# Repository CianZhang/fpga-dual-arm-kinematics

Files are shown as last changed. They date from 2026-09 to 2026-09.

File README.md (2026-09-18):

# 双机械臂机械结构设计与 FPGA 逆运动学实现

**Mechanical Design and FPGA Inverse Kinematics for a Dual-Arm Robot**

**第九届全国大学生集成电路创新创业大赛全国二等奖作品**

在这个项目中，我的主要工作是基于现有 STL 方案的机械结构补充设计，以及 Delta 并联机械臂和平行四边形连杆机械臂的逆运动学 FPGA 实现。本仓库围绕结构参数、数学模型、Verilog 定点计算与实物系统之间的对应关系整理。

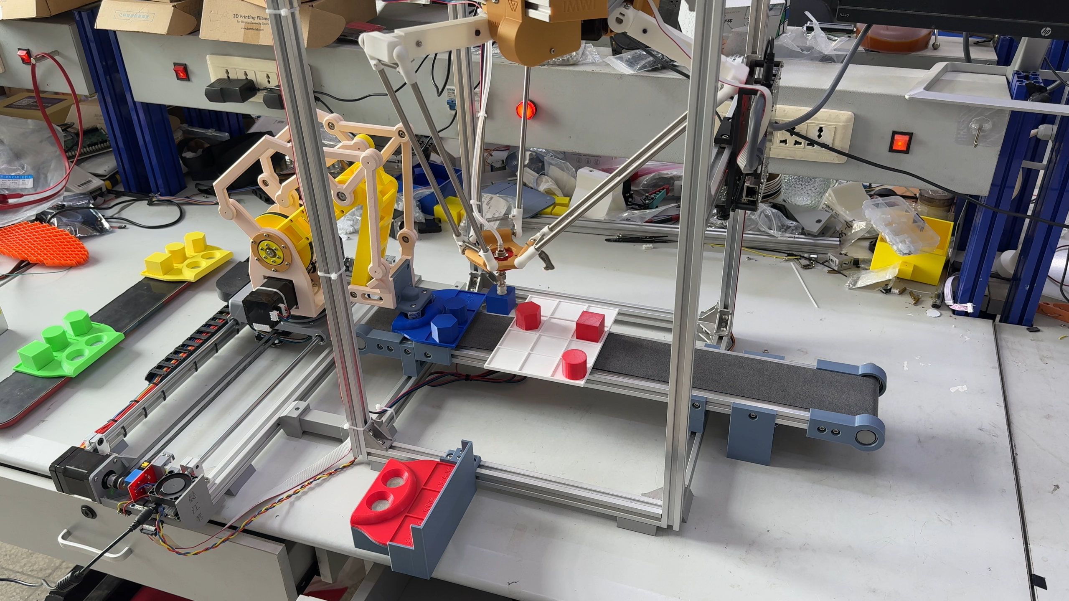
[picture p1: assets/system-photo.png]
双机械臂分拣系统实物，摘自比赛设计报告


> 摄像头采集与 FPGA 视觉识别由其他团队成员完成，本仓库保留运动控制侧的接口和系统背景，不包含视觉工程源码。两套机构基于网络 STL 方案，我补充了部分结构；仓库收录本人建模的 SolidWorks 源文件，详见[贡献与来源](docs/contributions.md)。

## 主要工作

- **机械结构补充设计**：基于网络 STL 机构方案补充结构并完成 SolidWorks 建模，结合分拣任务进行安装与配套设计。结构参数与解算代码对照展示。
- **两类机械臂逆运动学**：将目标空间坐标转换为驱动关节角度，再连接步进电机控制模块。
- **定点运算实现**：以整数缩放、位宽规划和移位处理实现原本的浮点计算；Delta 输入坐标采用 ×16 编码，电机角度采用 ×256 编码。
- **资源复用**：通过状态机调度乘法器，配合迭代开方和串行 CORDIC，在资源与计算延迟之间进行取舍。

仓库同时保存原项目中的线性插补、电机控制和串口等配套模块，以便理解完整调用链；这些文件的收录不代表其中每一行都是独立原创。

## 系统关系

```mermaid
flowchart LR
    V[视觉识别板
其他团队成员实现] -->|UART 识别结果| C[分拣与路径控制]
    U[上位机指令] --> C
    C --> D[Delta 逆运动学]
    C --> L[连杆机械臂逆运动学]
    D --> M[步进电机脉冲与方向]
    L --> M
    M --> H[双机械臂与平移机构]
```

## 结果与证据

以下 FPGA 数据来自比赛设计报告，是历史仿真与工程记录，并非本次重新上板测得。

| 项目 | 原报告结果 | 解释 |
| --- | --- | --- |
| Delta 完整逆解 | 50 MHz，235 个周期，约 4.7 μs | 算法解算耗时，不是机械臂完成运动的时间 |
| 单点角度对比 | 约 0.0048° 差异 | 坐标 (0, 0, −237.5 mm)，不是全工作空间最大误差 |
| 两套逆解算术资源 | 报告记录为 16 APM | 整机资源图显示 30/30 APM，不能混用统计范围 |
| 机械结构与实物 | 装配图、尺寸图、实物图 | CAD 来源与版本状态见 mechanical |

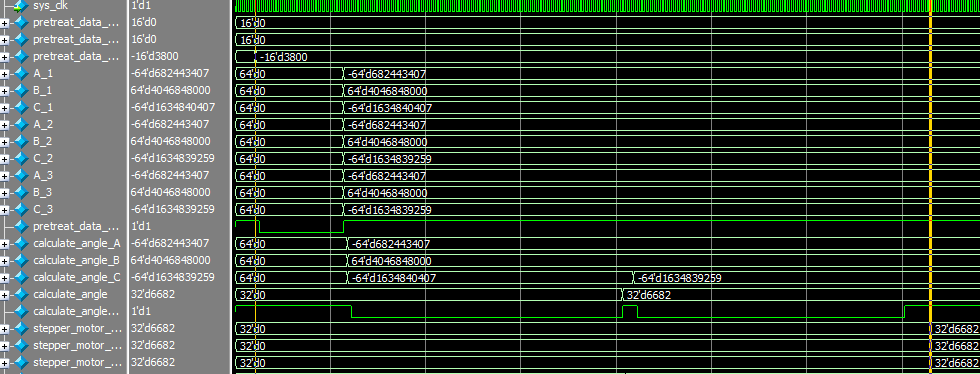
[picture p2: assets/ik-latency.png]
Delta 逆解历史仿真波形


[查看验证记录与限制](docs/validation.md) · [阅读 FPGA 实现](docs/fpga-implementation.md)

## 从哪里开始

1. 阅读[机械结构设计](docs/mechanical-design.md)，了解尺寸与坐标约定。
2. 阅读[逆运动学说明](docs/inverse-kinematics.md)，对照公式与模块。
3. 在仓库根目录执行 Python 参考计算：

   ```sh
   python3 reference/delta_inverse.py --x 0 --y 0 --z -237.5
   ```

4. 使用 Pango Design Suite 打开 `fpga/pango/top_delta_ctrl.pds` 前，按[复现说明](docs/reproduce.md)生成乘法器 IP 并配置仿真库。

原 RTL 按比赛版本保存。当前整理版已检查文件来源、工程输入路径及 Python 样例；尚未重新完成 PDS 综合、HDL 仿真或实物测试。

## 目录

| 目录 | 内容 |
| --- | --- |
| `rtl/delta/` | Delta 逆解与配套控制 |
| `rtl/linkage_arm/` | 连杆机械臂逆解与配套控制 |
| `sim/` | 原比赛仿真源文件，按两套机械臂分开 |
| `reference/` | Python 参考计算及历史脚本 |
| `mechanical/` | 本人 SolidWorks 模型、外部模型清单和来源说明 |
| `fpga/pango/` | 调整路径后的集成工程、原约束与 IP 配置说明 |
| `docs/` | 设计说明、贡献说明、验证记录和原报告 |
| `assets/` | 从原设计报告提取的结构与验证图片 |

原设计报告见 [PDF](docs/report/CICC0900959_design_report.pdf) 和 [Word](docs/report/CICC0900959_design_report.docx)。报告描述整个团队系统；个人贡献以上述边界为准。原报告、代码与历史脚本中的差异已在文档中列出。

## 来源与使用说明

参见 [THIRD_PARTY_NOTICES.md](THIRD_PARTY_NOTICES.md)。本次整理没有替项目选择开源许可证；厂商专有 IP 源码未纳入，需在本地生成。机械模型保留原目录名称，以便追溯来源。

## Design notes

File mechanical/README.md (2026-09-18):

# 机械结构补充设计

两套机械臂以网络公开的 STL 方案为基础，项目作者在此基础上自行建模并补充部分结构。作者确认：原资料中的 STL 属于网络参考材料，SolidWorks 源文件为本人建模。本仓库据此收录 `.SLDPRT` 与 `.SLDASM`，不把整体机构方案声明为独立原创。

`solidworks/` 保留原建模目录层级，以减少装配相对引用变化。建模归属并不表示每个零件的机构原理或外形都是首次设计；个人贡献应表述为基于现有方案的建模与结构补充。

| 原目录 | 整理方式 |
| --- | --- |
| Delta建模 | 收录其中的 SolidWorks 源文件，包含配套支架、安装件与结构件 |
| 2022delta | 收录 SolidWorks 源文件；目录名保留为来源标识，不据此判定制作年份或最终版本 |
| 带滑轨的步进电机机械臂 | 收录其中的 SolidWorks 源文件，例如泵托与泵托盖 |
| 网络 STL | 只记录清单和来源线索，不随仓库重新分发 |
| 3MF 等其他格式 | 留在原资料中，清单注明未纳入 |

[浏览 96 个 SolidWorks 文件索引](parts-index.md)。

全部机械文件清单见 [source-inventory.json](source-inventory.json)，实际收录文件见 [solidworks](solidworks/)。原 STL 来源线索见 [第三方说明](../THIRD_PARTY_NOTICES.md)。

未在本次整理中使用 SolidWorks 打开 / 重建装配，也未生成 STEP。由于外部 STL 和可能存在的外部装配依赖未随仓库分发，装配打开后的缺失引用需要在 CAD 软件内核对。报告中的装配截图用于浏览展示，不代表已完成装配文件完整性验证。

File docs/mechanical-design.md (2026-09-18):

# 机械结构设计

两套机构基于网络 STL 方案，作者自行建模并补充部分结构。结构设计的展示重点是几何尺寸与算法参数的对应，以及两套机构如何配合分拣任务。图片均摘自原比赛设计报告，未重新渲染 CAD。

## Delta 并联机械臂

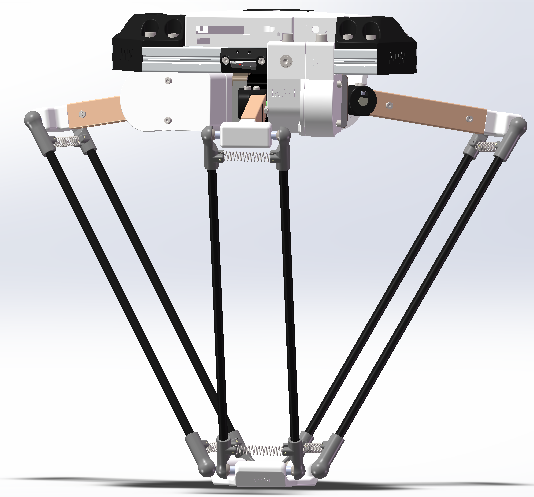
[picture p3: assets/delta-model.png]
Delta 结构

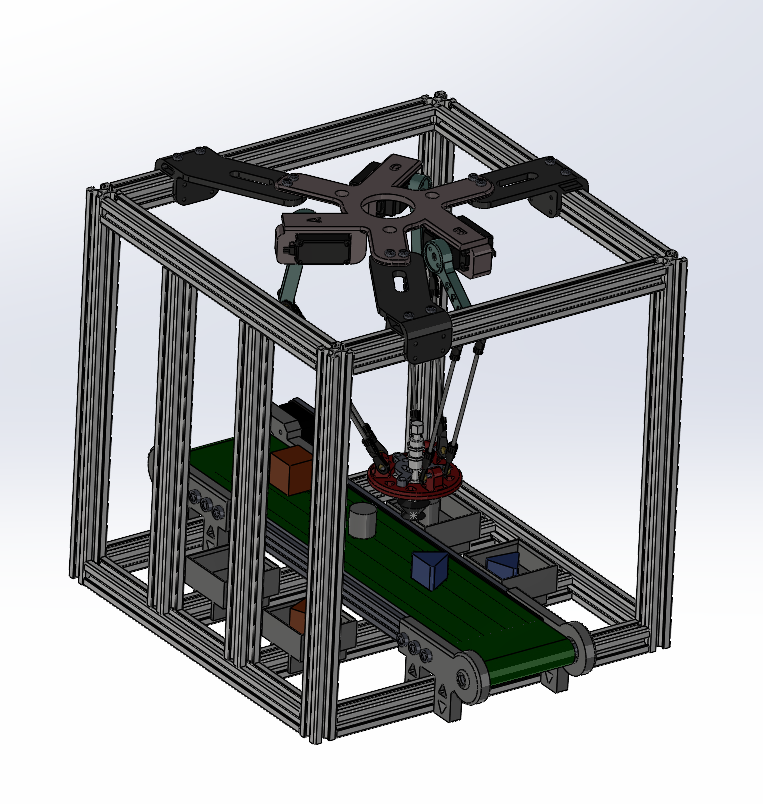
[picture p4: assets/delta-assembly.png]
整机框架装配


| 参数 | 数值 | 对应位置 |
| --- | --- | --- |
| 主动臂长度 m | 130 mm | `pretreat_data.v` 与原 Python 逆解 |
| 从动臂长度 n | 316 mm | 同上 |
| 静平台半径 R | 74.6920 mm | 同上 |
| 动平台半径 r | 34.6410 mm | 同上 |
| 铝型材框架 | 400 × 400 × 600 mm | 报告 3.2.1 |

报告给出的工作范围为 X/Y 约 −170 至 170 mm、Z 约 −400 至 −200 mm。这些数值不能当作长方体内每一点都可达的保证，还需考虑机构约束、碰撞与解的分支。

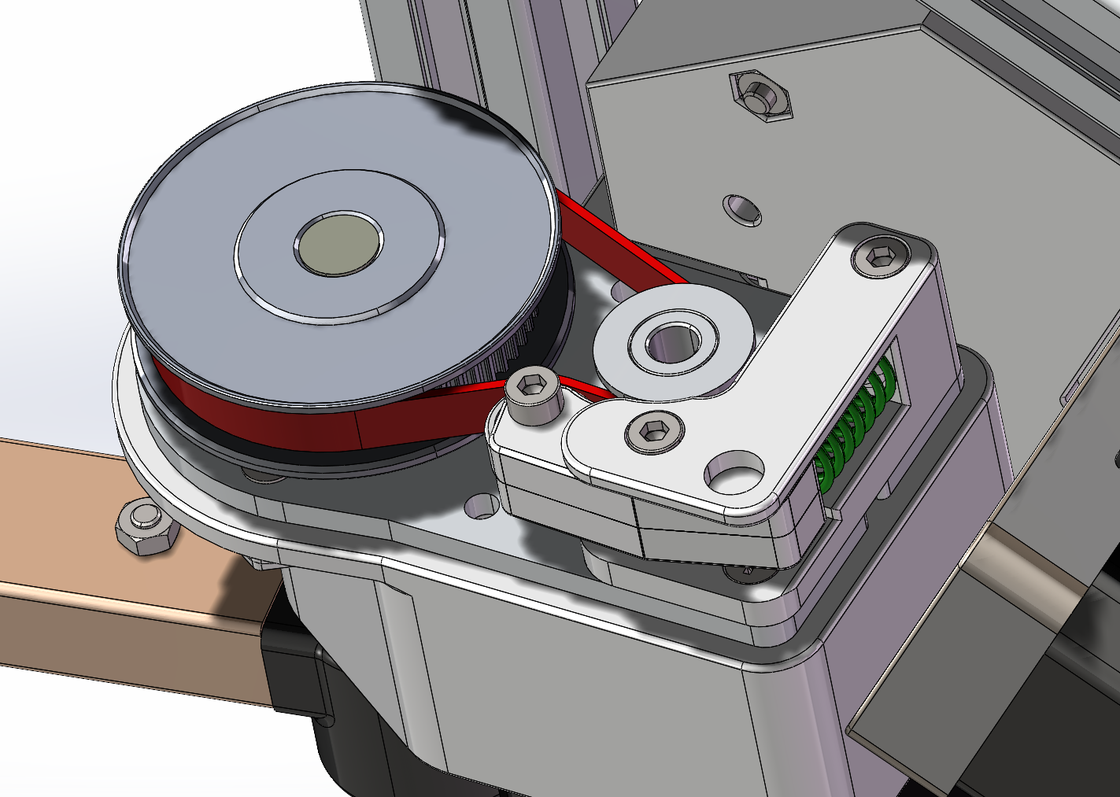
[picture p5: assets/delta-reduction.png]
报告中的减速结构


`pretreat_data.v` 中尺寸相关计算已经展开成整数常量，原注释明确指出修改尺寸 localparam 不会自动改变计算。更换结构时应重新推导全部相关常量并验证。

## 连杆机械臂与平移轴

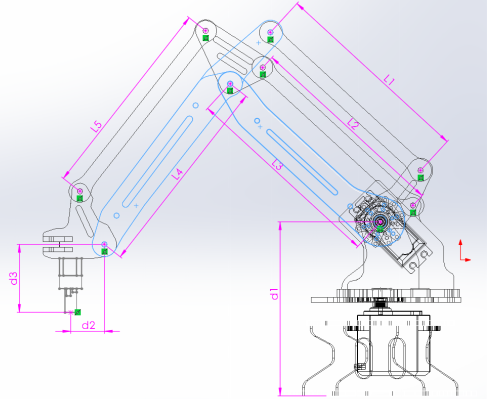
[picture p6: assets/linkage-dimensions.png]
连杆机械臂尺寸草图


平行四边形连杆机构用于托盘搬运，报告描述在三轴机构基础上增加 Y 方向平移轴以扩展工作范围。当前 `solver_big_and_small_arm.v` 中的参数为：大臂 150 mm、小臂 150 mm、起始升高量 95 mm、末端前伸量 65 mm、末端下降量 58 mm。调参时还需要同步检查长度平方与乘积常量。

## 模型归档

[mechanical](../mechanical/README.md) 保存原目录组织、CAD 文件清单和来源边界。SolidWorks 装配可能包含外部引用；本次没有使用 SolidWorks 打开重建，不保证归档中的装配引用全部完整，也没有将源文件改扩展名伪装为 STEP。

历史 `reference/legacy/delta_workspace_original.py` 使用 R=60、r=35、L=100、La=350，与上述比赛参数不同，且存在原有缩进问题。它仅作历史参考，不作为最终尺寸的验证依据。

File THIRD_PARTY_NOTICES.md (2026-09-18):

# 第三方材料与来源说明

## 厂商 FPGA IP

原项目的 `ip_multiplier.v` 和 `ipml_mult_v1_3_ip_multiplier.v` 含 Pango 专有源码声明。本次整理未收录其源代码，替换为本地生成参数说明。FPGA 器件原语与 ModelSim 库由本机 PDS 安装提供。

## 机械参考资料

原 `建模/readme.txt` 留有以下来源线索，本次未在线核验页面及其许可证：

- https://www.thingiverse.com/thing:6422152
- https://www.thingiverse.com/thing:6425752
- https://www.bilibili.com/video/BV18S4y1A76F/

目录还包含 Delta-X 相关模型 / 学习资料。作者确认网络 STL 是参考方案，SolidWorks 源文件为本人建模，个人贡献是补充部分结构。`mechanical/solidworks` 仅收录 SolidWorks 源文件，外部 STL 不随仓库分发。两套机械臂的整体机构方案不声明为个人原创。

## 配套控制例程

原报告 3.7.2 / 3.7.3 附近说明 I²C 实现参考了正点原子例程。仓库保存原文件中的现有注释，收录不等于声明配套控制模块全部独立原创。

## 团队作品与报告

原报告、实物照片和整机证据属于团队项目背景。视觉识别由其他团队成员完成；本仓库个人成果重点为机械结构设计和 FPGA 逆运动学实现。

本次整理没有添加 MIT、Apache 等覆盖全部材料的许可证，也没有移除原文件中的署名。未明确许可的参考模型需确认来源条款后再决定公开分发范围。

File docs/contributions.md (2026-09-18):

# 贡献与来源

## 个人工作范围

依据项目作者的说明，个人重点工作为机械结构设计及机械臂逆运动学解算的 FPGA 算法实现。技术材料来自 `CICC0900959_设计报告`，尤其是 3.2、3.3、4.1.3、4.1.4 节。报告中的“我们”描述团队项目，不作为每个文件作者身份的证明。

| 内容 | 仓库处理 |
| --- | --- |
| 机械结构设计与逆运动学 FPGA 实现 | 首页重点展示 |
| 摄像头采集、视觉识别 | 其他团队成员负责；不收录视觉源码 |
| 步进控制、路径规划、UART、传感器等 | 保存原项目配套源码，未逐文件断言独立原创 |
| 上位机 Qt 项目 | 首版不收录，避免分散核心主题 |
| 厂商乘法器 IP | 不收录厂商源码，记录生成参数 |
| 外部机械模型和教程 | 保留来源线索；混合模型目录不整体声明原创 |

## 机械模型的来源边界

作者已确认：两套机械臂以网络 STL 方案为基础，本人补充了一部分结构；资料中的 STL 是网络参考材料，SolidWorks 源文件为本人建模。因此仓库机械贡献表述为“基于现有 STL 方案的结构补充设计与 SolidWorks 建模”，不称为两套机构完全从零原创。

`mechanical/solidworks/` 收录 SolidWorks 源文件并保留原目录名。外部 STL 只列来源清单，不随本仓库分发。3MF 等其他格式保留在原资料中。

原 `建模/readme.txt` 的两个 Thingiverse 链接和 Bilibili 教程是参考来源线索，尚未逐个对应到每个零件。整体方案来源与本人源文件归属分别说明，不用文件扩展名推断机构方案原创性。

## 本次整理新增内容

Markdown 说明、Python 命令行参考入口、文件清单与校验工具属于本次整理新增内容，不应追溯描述为比赛期间已完成的成果。原 Verilog 源码保持字节内容不变；集成 PDS 工程仅调整输入路径、乘法器生成位置并清除旧机器的仿真工具路径。

全部已复制材料的原相对位置和 SHA-256 见 [source-manifest.json](source-manifest.json)。

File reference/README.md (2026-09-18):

# Python 参考材料

`delta_inverse.py` 为本次整理新增的标准库命令行入口，沿用原反解的结构尺寸、0.8660 近似与角度分支。默认输入单位为毫米，输出物理电机命令角及 ×256 编码值。

`legacy/delta_inverse_original.py` 是原 `建模/DeltaX/运动学反解.py`，字节内容未改变。

`legacy/delta_forward_original.py` 和 `legacy/delta_workspace_original.py` 仅作为历史参考；其参数不能自动视为最终机械臂尺寸。工作空间脚本存在原有缩进问题，本次没有悄悄修复并把结果当作原比赛证据。若使用这些旧脚本，需另行安装 numpy / matplotlib 并先核对模型。

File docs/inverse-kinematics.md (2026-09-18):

# 逆运动学与坐标约定

## Delta 机械臂

原模型中 m、n 分别为主动臂与从动臂长度，R、r 分别为静平台与动平台半径。令 d=r−R，三个分支对应的系数为：

```text
A1 = 2m(d+x)
B1 = -2mz
C1 = (d+x)² + y² + z² + m² - n²

A2 = 2m(d-x/2+√3·y/2)
B2 = -2mz
C2 = (d-x/2+√3·y/2)² + (√3·x/2+y/2)² + z² + m² - n²

A3 = 2m(d-x/2-√3·y/2)
B3 = -2mz
C3 = (d-x/2-√3·y/2)² + (√3·x/2-y/2)² + z² + m² - n²
```

这些系数进入 `A sin(θ) + B cos(θ) = C` 的求解。原脚本使用 √3/2≈0.8660；整理新增的 Python 入口默认沿用该近似，便于对照原脚本。

原实现选择的计算分支：

```text
D = A² + B² - C²
N = -A·B - C·sqrt(D)
Q = A² - C²
θ = atan(N/Q)，按原程序规则调整至所需角度分支
电机命令角 = 130° - θ
```

`reference/delta_inverse.py` 返回原模型相同分支下的电机命令角。它会拒绝负判别式和零分母；并未加入完整碰撞检测、机械限位或所有奇异情况的替代解，不能直接充当任意机器人通用逆解库。

报告对比点的物理坐标为 `(0, 0, -237.5)` mm，RTL 输入编码为 `(0, 0, -3800)`。不要把编码值直接当成毫米。

## 连杆机械臂

`arm_motion_solver.v` 先处理空间坐标：旋转轴由 XY 投影求角，大小臂使用平面距离与高度求解。`solver_rotation.v` 含旋转方向选择，`solver_big_and_small_arm.v` 包含连杆长度、末端偏移与角度处理。平移轴由上层控制与对应电机模块处理，不能把三关节解算模块等同于完整四轴规划器。

详细几何图与推导保留在原报告 3.3 节。本次没有另写未经验证的连杆机械臂 Python 参考模型。

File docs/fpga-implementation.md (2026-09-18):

# FPGA 实现

## 阅读顺序

| 功能 | 入口 |
| --- | --- |
| 集成系统顶层 | `rtl/delta/delta_ctrl/top_delta_ctrl.v` |
| Delta 解算调度 | `rtl/delta/motion_solver/motion_solver.v` |
| 坐标预处理 | `rtl/delta/motion_solver/pretreat_data.v` |
| 单关节角度求解 | `rtl/delta/motion_solver/calculate_angle.v` |
| CORDIC 与开方 | 同目录 `cordic_serial.v`、`sqrt.v` |
| 连杆机械臂解算 | `rtl/linkage_arm/motion_solver/arm_motion_solver.v` |
| 大小臂与旋转轴 | 同目录 `solver_big_and_small_arm.v`、`solver_rotation.v` |

## 定点格式

Delta 输入为 16 位有符号坐标编码，物理毫米值乘 16；ABC 系数使用 64 位有符号寄存器，原设计按 ×65536 缩放。CORDIC 角度输出按 ×65536 表示，`calculate_angle` 最终执行 `33280 - (raw_angle >> 8)`，对应 `(130° - θ) ×256`。

这些模块使用混合缩放与截位，不能将所有信号统一描述为某一种 Q 格式。核对误差时需要逐级追踪缩放、符号位、乘法输入截取和输出右移。

## 分时复用与调度

`pretreat_data` 通过状态机将不同操作数送入同一个 32×32 位乘法器实例。`calculate_angle` 使用另一个乘法器实例处理平方和与后续乘积，并调用开方与 CORDIC 模块。Delta 顶层复用单个 `calculate_angle` 实例依次处理三个分支；源码头部“同步解算”不应被解读成三套完全并行的角度计算硬件。

报告 4.1.3 记录预处理 23 周期、单关节计算约 70 周期、完整 Delta 解算 235 周期。报告其他位置也出现“14 周期”等不同描述，因此仓库只把 235 周期作为报告的历史整体数据，不将不同层级的时延混在一起。

## 算法完成与运动完成

当前 `motion_solver` 同时实例化步进电机控制器，外部输出是电机脉冲、方向和完成状态。评估纯算法延迟应观察内部角度结果与计算阶段，不能直接把包含电机运动的完成信号当作逆解延迟。

部分计算单元靠输入变化触发，接口并不是标准 `start/valid/ready` 协议。重复相同输入、复位后零值和连续输入需要专门检查；本次保留原比赛行为，没有借整理机会修改算法接口。

## 工程相关

原集成工程同时引用两类机械臂，但 UART 文件存在多个历史版本。整理版按照集成 PDS 的选择，保留 `fpga/pango/source/uart/` 两个工程局部版本；不要递归导入整个 RTL 目录，否则可能产生同名模块冲突。

乘法器生成参数与文件位置见 [IP 配置说明](../fpga/pango/IP_CONFIGURATION.md)。

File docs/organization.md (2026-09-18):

# 归档范围与版本选择

整理以比赛提交目录 `代码/CICC0900959_Project/CICC0900959_Project` 的 RTL 和集成工程为基线。两套 `motion_solver` 文件夹已与 `代码/Project` 对应版本比较，内容一致；不据此推断其余文件全部相同。

保留：两套机械臂 RTL、原仿真源码、一个集成 PDS 工程及约束、原 Python 参考脚本、机械模型、报告及精选图片。

排除：OV5640 视觉工程、工具安装包、厂商资料全集、账单、重复项目副本、构建产物、波形数据库、上位机 ZIP、PSD 和海报模板。原完整演示视频约 523 MB，留在原资料中，首版以报告实物图展示；未伪造视频链接。

修改范围：PDS 源码引用重定位；厂商 IP 引用改为本地生成路径；清除旧机器的 ModelSim 路径。RTL 和原测试源码保持不变。新增文档及工具在贡献说明中单独标记。

根据作者确认，只收录本人建模的 SolidWorks 源文件并保留原目录结构。网络 STL 和其他模型格式只列清单，不重新分发。机械贡献为现有方案基础上的结构补充设计，未对无法打开的装配作完整性保证。

源文件追溯：`source-manifest.json`；机械文件总表：`../mechanical/source-inventory.json`；整理校验结果：`organization-check.json`。

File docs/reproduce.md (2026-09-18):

# 复现说明

## Python 参考计算

在仓库根目录运行（Python 3，仅需标准库）：

```sh
python3 reference/delta_inverse.py --x 0 --y 0 --z -237.5
python3 reference/legacy/delta_inverse_original.py
python3 tools/check_repository.py
```

第一个入口是整理时新增的命令行工具；第二个是未改动的原始样点脚本。两者仅验证浮点参考计算，不代表 RTL 已通过验证。

## FPGA 集成工程

整理版工程：`fpga/pango/top_delta_ctrl.pds`。

原 PDS 头部记录工具版本 `2022.2-SP4.2`，器件为 Logos / PGL22G / MBG324 / speed grade −6。系统源码注释和原仿真使用 50 MHz 时钟。资料目录中的 2021.1 安装包不作为本工程的实际构建版本依据。

1. 按 `fpga/pango/IP_CONFIGURATION.md` 在本地生成 `ip_multiplier`，放到指定目录。
2. 使用 PDS 打开工程。若新版 IP 生成层级不同，在工程中替换两项 IP 文件引用，并纳入生成工具要求的其余文件。
3. 确认顶层为 `top_delta_ctrl`，输入源码与 `fpga/pango/sources.f` 一致。该清单路径相对于 `fpga/pango/`。
4. 导入原引脚约束 `top_delta_ctrl_IO.fdc`，根据实际板卡、接线和时钟约束核对后再生成下载文件。
5. 如需 ModelSim，设置本机工具路径并编译 / 映射匹配版本的 Pango 仿真库。整理版清除了原机器的工具路径。

厂商 IP 尚未生成时，工程不是开箱即编译的状态。本次只核对了文件路径，不承诺工具版本兼容或时序通过。

## 仿真入口

- 集成系统：`sim/delta/tb_top_delta_ctrl.v`。
- Delta 逆解与电机：`sim/delta/tb_motion_solver.v`。
- 连杆机械臂：`sim/linkage_arm/tb_motion_solver/` 下的原测试文件。

各测试工程应分别选择依赖文件。不要将所有 `test/` 和 `sim/` 文件一次性加入同一个工程，其中存在同名顶层及历史模块版本。测试文件中的 `GTP_GRS` 等原语依赖厂商仿真库。

## CAD

机械文件保持原文件名与相对层级，参见 `mechanical/README.md`。本次未执行 SolidWorks 装配重建或 STEP 导出。不要仅凭仿真坐标范围直接对真实机械臂发送运动命令；零点、限位与接线需和原硬件一致。

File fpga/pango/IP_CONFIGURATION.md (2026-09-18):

# 乘法器 IP 配置

原 `ip_multiplier.v` 与其底层实现带有 Pango 专有声明。本仓库不附带这两个厂商源码文件，以下参数来自原工程配置，供本地重新生成。

| 参数 | 原值 |
| --- | --- |
| 模块名 | ip_multiplier |
| ASIZE / BSIZE | 32 / 32 |
| A_SIGNED / B_SIGNED | 1 / 1 |
| 输出宽度 | 64 |
| INREG_EN | 0 |
| PIPEREG_EN_1 / 2 / 3 | 0 / 0 / 0 |
| OUTREG_EN | 0 |
| ASYNC_RST | 1 |
| OPTIMAL_TIMING | 0 |
| GRS_EN | FALSE |
| 端口 | ce, rst, clk, a[31:0], b[31:0], p[63:0] |

当前整理版 PDS 预期文件：

```text
generated/ip_multiplier/ip_multiplier.v
generated/ip_multiplier/rtl/ipml_mult_v1_3_ip_multiplier.v
```

生成目录已被 `.gitignore` 排除。生成器版本可能改变底层文件名或附加依赖，届时应通过 PDS 添加实际生成文件。原配置未启用输入、流水或输出寄存器，不能随意开启流水级而不调整调用状态机。未提供替代行为模型，避免把未经核对的替代实现当作原厂 IP 的验证结果。

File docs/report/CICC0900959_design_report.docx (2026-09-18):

第九届

全国大学生集成电路创新创业大赛

报告类型*： 设计报告

参赛杯赛*： 紫光同创杯

作品名称*： 基于FPGA的双机械臂协同控制系统设计

队伍编号*： CICC0900959

团队名称*： 我来带队

# 1 作品介绍

## 1.1 项目背景介绍

随着智能制造和工业4.0的快速发展，自动化流水线在提升生产效率、优化资源分配以及增强生产灵活性方面的需求日益增长。分拣任务作为自动化流水线中的核心环节，直接影响生产线的整体效率和可靠性。该任务要求系统具备高实时性以应对动态工作环境、高精度以确保分类准确性，以及良好的适应性以处理多样化的物体摆放方式。然而，传统分拣系统通常依赖单一的机械结构和低速处理单元，其算法复杂性和硬件限制难以满足传送带上随机摆放物体的高效动态分拣需求。此外，传统系统在面对多类型、多姿态物体的识别与分拣时，往往存在响应延迟或误判率较高的缺陷，限制了其在现代工业生产中的广泛应用。

为解决上述问题，本项目提出了一种基于FPGA的双机械臂协同控制系统。该系统通过集成高分辨率OV5640双目摄像头以及两种机械臂（Delta机械臂和平行四边形连杆机械臂），实现了传送带上物体的快速识别与精准分类分拣。FPGA凭借其高并行处理能力和低延迟特性，显著提升了系统的实时性能；OV5640摄像头提供高质量的视觉输入，结合双机械臂的协同操作，优化了分拣流程的效率和准确性。该设计为工业4.0背景下的自动化流水线提供了高效、可扩展的解决方案，具备较强的工程应用价值和未来升级潜力。

## 1.2 作品介绍

本项目以两块紫光同创PGL22G开发板为核心硬件平台，分别控制Delta机械臂、平行四边形连杆机械臂以及OV5640双目摄像头，构建了一个完整的物体分拣系统。

图1.1 紫光同创PGL22G 图1.2 双目摄像头

具体实施流程如下：

首先，操作人员在初始托盘上随机摆放12个物体，涵盖四种颜色（红、蓝、黄、绿）和三种形状（圆形、方形、六角形），形成多样化的分拣目标。摆放完成后，托盘通过传送带运输至OV5640双目摄像头下方进行识别。摄像头利用立体视觉技术实时分析物体的颜色和形状，并通过HDMI接口输出视频流，显示识别结果，包括物体的位置、颜色和形状信息。这一阶段确保了视觉识别的高效性和直观性，为后续分拣操作提供了准确的数据基础。


识别完成后，传送带将托盘移动至Delta机械臂的操作区域。Delta机械臂负责根据识别结果，依次拾取托盘上的物体，并将其按颜色分类放置至对应的目标托盘中。与此同时，平行四边形连杆机械臂协同工作，负责提供新的空托盘以支持连续分拣操作。具体而言，当Delta机械臂完成某一颜色物体的放置（例如将三个红色物体放入一个托盘）后，平行四边形连杆机械臂将当前托盘移走，并取回一个新的空托盘。上述过程循环进行，直至12个物体全部分类完成。该系统通过双机械臂的分工协作和FPGA的高效控制，实现了从识别到分拣的全自动化流程，显著提高了分拣效率和可靠性。

图1.3 作品实物图

## 1.3 作品完成清单

根据赛题要求，本作品模拟了工业生产线上多个机器人实现低延迟、高精度协同控制的场景，成功实现了Delta机械臂与平行四边形连杆机械臂的智能协作分拣功能，贴近实际工业自动化应用需求。

基础任务

- 机器人运动控制 系统实现了步进电机的梯度加减速算法控制（报告2.2章节）。同时基于Verilog实现了Delta机械臂与平行四边形连杆机械臂的逆运动学解算（报告2.3章节）。
- 传感器数据处理 系统集成了RFID射频标签读取功能，可准确识别托盘的唯一编号，真实模拟了工业场景中的物流运输过程。
- 人机交互接口 上位机提供了直观的控制和监控界面，支持手动输入坐标或一键执行预设路径（报告2.9章节）。HDMI显示模块处理双目摄像头数据，实时呈现物体识别结果（报告2.7章节）。

进阶任务

- 低延迟高精度反馈 系统通过I²C接口与VL6180X距离传感器通信，集成于Delta机械臂末端，实时感知环境距离，距离数据反馈优化了吸取路径（报告2.8章节）。
- 感知与目标识别 利用FPGA处理双目摄像头采集的720P数据，实现了目标物体的颜色识别与形状识别（报告2.5、2.6章节）。
- 多机器人协作 Delta机械臂与平行四边形连杆机械臂实现协同工作，Delta机械臂负责物体拾取与分类放置；连杆机械臂通过磁吸方式搬运托盘（报告2.4章节）。

本作品设计充分考虑了实际工业场景的需求，结合低延迟（逆运动学解算4.7微秒）、高精度（定位误差≤1毫米）和多机器人协作，成果可广泛应用于工业自动化领域，如智能分拣、物流运输和柔性制造系统，为提升生产效率和智能化水平提供了技术支持。

# 2 作品核心功能

## 2.1 系统框图

本系统采用模块化设计架构，整体功能划分为两大相互协作的板块，分别部署在两块紫光同创PGL22G开发板上，借助串口通信实现高效的数据交互与协同控制，确保系统运行的稳定性和实时性。

第一板块主要负责视觉识别与数据处理，集成了OV5640双目摄像头和HDMI显示器，作为系统的感知核心，负责物体的图像采集、处理与分类识别。这些识别结果不仅通过HDMI接口以视频流形式实时输出，供操作人员直观监控，还通过串口传输至第二板块，为机械臂分拣提供指导。

第二板块专注于机械臂的控制与路径规划，连接Delta机械臂和平行四边形连杆机械臂，负责执行物体的物理分拣任务。通过串口从第一板块获取物体位置和分类信息，随后路径规划模块根据这些数据为两套机械臂分别设计优化运动轨迹。路径规划过程结合逆运动学解算模块，精确计算两机械臂的关节角度，确保运动轨迹的流畅性和协同性，从而实现高效的分拣流程。

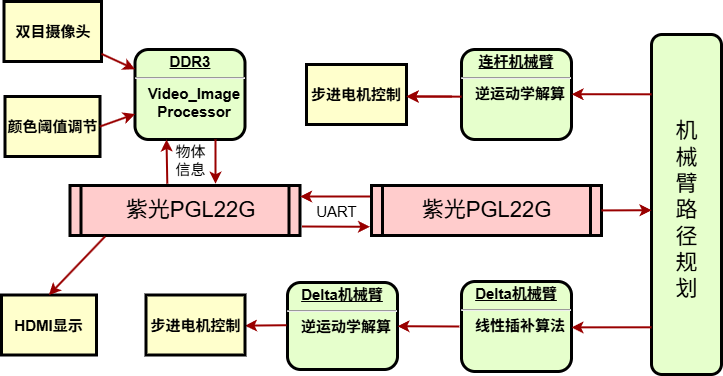
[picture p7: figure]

此外，系统设计中融入了人机交互功能，两块板卡均支持上位机控制，操作人员可通过PC软件发送指令，灵活调整机械臂的姿态、暂停分拣流程或进行手动干预。

图2.1 系统框图

## 2.2 步进电机梯度加减速控制

在本系统中，Delta机械臂和平行四边形连杆机械臂均采用步进电机作为驱动单元，FPGA通过高精度脉冲信号精确控制电机旋转角度，实现末端执行器的精准定位与运动控制。然而，初期采用固定频率脉冲信号驱动步进电机，导致运动启停阶段出现剧烈抖动，显著降低定位精度。

为解决此问题，系统在步进电机控制模块中引入梯度加减速算法，通过动态调整脉冲频率实现平滑的加速与减速过程，有效消除速度突变引发的振动和失步现象。该算法分为三个阶段：加速阶段，脉冲频率从低值逐步增至目标频率；匀速阶段，维持恒定频率确保运动连续性；减速阶段，频率渐降至零，实现平滑停止。此策略显著改善机械臂动态响应，减少因惯性或负载变化导致的机械振动。

针对Delta机械臂和平行四边形连杆机械臂各轴的负载特性和运动需求差异，系统为每轴定制独立加减速比例参数，通过FPGA灵活配置实现个性化优化。这些参数根据轴的惯量、负载重量和运动距离动态调整，确保加减速曲线匹配实际工况。

图2.2 步进电机梯度加减速算法

## 2.3 逆运动学解算

### 2.3.1 Delta机械臂逆运动学解算

Delta机械臂是系统核心执行部件，负责物体精准抓取与分类放置，其运动控制依赖高效的逆运动学解算模块。逆运动学解算的目标是将末端执行器三维空间目标位置（X, Y, Z）映射为三个驱动臂的关节角度，涉及复杂的几何计算和反三角函数运算。为此，系统采用CORDIC算法，通过串行计算实现高效反三角函数求解，仅需17个时钟周期即可输出高精度结果，兼顾计算稳定性和时间效率。

逆运动学解算需大量乘法运算，对FPGA算术资源要求较高。系统集成了紫光同创乘法器IP核以加速矩阵运算和坐标变换，但PGL22G芯片仅配备30个DSP乘法器，难以支持全并行运算。为优化资源利用，设计采用分时复用技术，将有限DSP资源分配给不同计算阶段，通过时序调度和流水线设计实现高效计算。尽管计算速度略有下降，但在PGL22G芯片上成功实现了逆运动学解算，确保了性能与资源的平衡。

### 2.3.2 平行四边形连杆机械臂逆运动学解算

平行四边形连杆机械臂是系统辅助组件，负责托盘抓取与更换，满足工业流水线高效搬运需求。相比传统三轴机械臂，其新增Y轴平移轴，显著扩展末端执行器运动范围，适应多场景托盘操作。该机械臂采用串联-并联混合结构，逆运动学解算需同时计算三个旋转关节角度和一个平移轴位移，计算复杂度较高。

为应对挑战，系统沿用紫光同创乘法器IP核的分时复用策略，并集成专用除法器模块优化算术运算。除法器采用硬件加速算法，仅需16个时钟周期完成32位除法。逆运动学解算通过几何模型解析末端位置与关节角度关系，结合分时复用和流水线技术同步计算四个电机目标角度。

## 2.4 机械臂路径规划

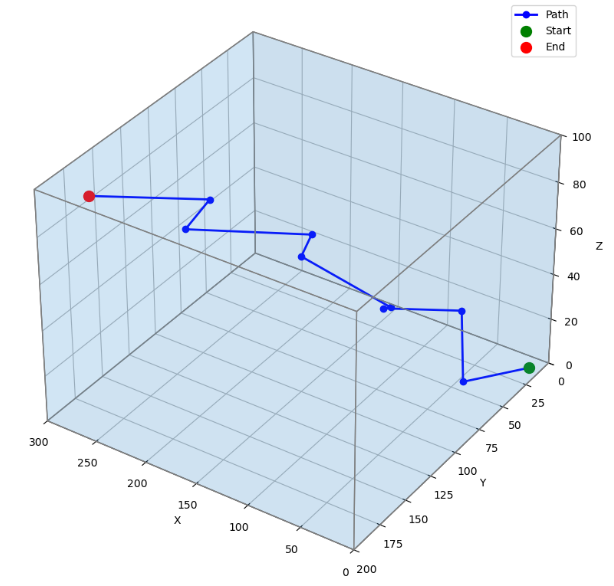
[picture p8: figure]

路径规划是机械臂控制系统的核心，直接影响运动轨迹平滑性、分拣精度和系统稳定性。Delta机械臂和平行四边形连杆机械臂分别针对其运动特性和任务需求，采用路径规划策略，实现高效协同操作，满足工业自动化流水线分拣要求。

图2.3 路径规划示意图

（1）Delta机械臂直线线性插补

Delta机械臂负责从传送带抓取物体并按颜色分类放置。为确保末端执行器三维空间运动平滑性，需解决各轴位移差值不一致引发的轨迹抖动问题。初期测试显示，位移较小轴提前到达目标点，导致末端执行器偏离直线路径，降低分拣稳定性和增加机械磨损风险。为此，设计引入直线线性插补算法，将各轴运动路径分为64段（利用FPGA移位操作特性），采用整数运算替代浮点运算，降低资源消耗。各轴步进步长根据最大轴差值同步调整，确保末端执行器沿直线平滑移动。优化后，轨迹平滑性显著提升，抖动现象几乎不可见，系统可靠性大幅增强。

（2）平行四边形连杆机械臂路径规划

平行四边形连杆机械臂负责托盘抓取与更换，需在铝材框架限制的狭窄空间内实现精准操作，面临碰撞风险和复杂运动约束。设计引入专用路径规划模块，通过优化大臂和小臂姿态，动态调整运动角度，避开框架并精确引导末端执行器到达目标位置。在托盘切换中，模块根据实时位置和姿态动态调整，兼顾安全性和定位精度，将定位误差控制在±1mm以内。该方案有效降低碰撞风险，提升机械臂在复杂环境下的适应性和稳定性，为协同分拣任务提供可靠保障。

## 2.5 OV5640双目摄像头数据采集

OV5640摄像头是系统视觉识别的核心组件，负责从传送带托盘内采集12个随机摆放物体的图像，为物体识别与定位提供高质量数据支持。该摄像头采用1.4μm×1.4μm像素尺寸，集成OmniBSI背照式感光技术，具有高灵敏度、低串扰和低噪声特性，能在复杂光照条件下输出清晰、稳定图像，适合工业视觉应用。其捕获的原始图像为后续颜色与形状识别提供可靠输入，确保分拣任务的准确性和实时性。

系统基于紫光同创PGL22G开发板，采用双目OV5640摄像头配置以实现立体视觉，获取物体深度信息，提升定位精度。通过I²C接口初始化配置OV5640，设置输出格式为720P@30fps的RGB565图像数据。RGB565格式以16位存储像素，兼顾图像质量与数据传输效率，适配FPGA高速处理能力。FPGA内部实现高效数据采集模块，结合双目摄像头例程，通过并行处理实时接收和缓存图像数据流。为应对工业环境光照变化，代码中包含了上位机通过串口调节颜色阈值，提升识别模块鲁棒性。采集数据经FPGA高速总线实时传输至图像处理模块，为物体识别、定位和高精度分拣提供稳定输入。以下是摄像头拍摄的原始图像。

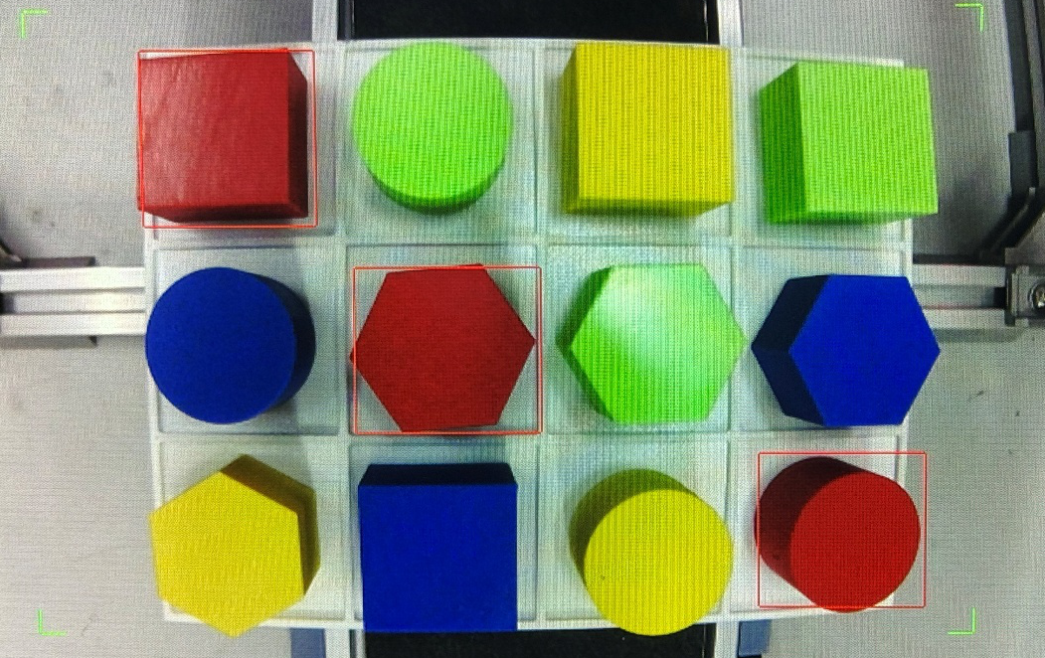
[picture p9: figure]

图2.4 摄像头画面

## 2.6 物体形状和颜色识别

物体形状与颜色识别模块是本系统视觉处理的核心组成部分，负责从OV5640摄像头采集的720P RGB565图像中提取12个随机摆放物体的颜色和形状特征，为Delta机械臂和平行四边形连杆机械臂提供精准定位数据，直接影响分拣任务的准确性和效率。为实现高效处理，该模块设计分为预处理和识别两个子模块，分别负责图像优化和特征提取。

预处理模块旨在提升图像质量，增强识别效果。首先将RGB565图像转换为HSV颜色空间，依据预设的红、蓝、黄、绿阈值提取目标区域。随后进行二值化处理，并根据噪声水平动态应用2至5次腐蚀操作，有效去除背景干扰，增强物体边缘轮廓，为后续识别提供清晰输入。

识别模块基于优化的车牌识别算法，结合面积计算和色块分离策略，实现高效物体初步分离，降低FPGA资源消耗。通过边界检测提取物体外接矩形框及几何中心，获取形状参数，准确区分圆形、正方形和六边形。

图2-4展示了物体形状与颜色识别的实际效果。该图包含四种颜色（红、蓝、黄、绿）和三种形状（圆形、正方形、六边形）的物体，反映了托盘内12个物体的随机摆放场景。图像的四个角以绿色线框标注，框定了识别范围，表明算法的工作区域。在识别范围内，红色方框精确框出识别到的红色物体，体现了模块在颜色和形状识别上的准确性，同时绿色线框与红色方框的结合直观展示了识别算法的定位能力，为系统的视觉处理性能提供了直观验证。

## 2.7 HDMI实时显示

HDMI实时显示模块在系统视觉识别与机械臂协同控制中至关重要，负责将OV5640双目摄像头采集的720P图像数据实时传输至外部HDMI显示设备，为操作人员提供直观监控界面。

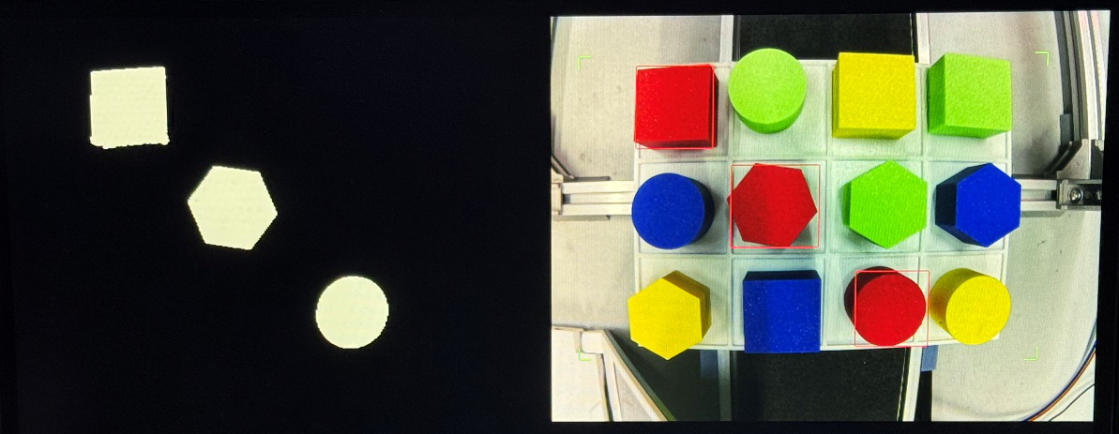
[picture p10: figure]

FPGA内部集成HDMI控制器，通过TMDS编码将RGB565格式图像数据转换为HDMI 1.4标准高速差分信号，输出至显示设备。为实现双目摄像头数据同步显示，设计调用两个video_rect_read_data模块，将屏幕划分为左右区域：左侧显示左目摄像头经二值化处理的图像，突出物体轮廓和颜色特征，便于评估预处理效果；右侧显示右目摄像头数据，结合识别算法结果，以画框标注物体颜色、形状及空间坐标。

图2.5 HDMI显示画面

## 2.8 VL6180距离传感器

VL6180X测距传感器是系统高精度定位的核心组件，专为Delta机械臂末端吸盘与托盘上12个随机摆放物体之间的距离测量设计，确保吸取动作的精准性和稳定性。该传感器采用飞行时间（ToF）技术，测量范围0~100 mm，标称精度±1 mm，支持高频采样，适配动态近距离定位场景，为Delta机械臂吸取操作提供可靠数据支持。

为实现与VL6180X的通信，系统在紫光同创PGL22G FPGA平台上开发了I²C软核模块，通过Verilog代码实现传感器配置（如单次测距模式）和数据采集。单次测距耗时约1 ms，I²C传输延迟优化后总响应时间低于传统串口方案。FPGA内集成的I²C控制模块通过优化时钟同步和数据缓冲机制，确保数据采集高效、无丢失。

为增强环境适应性，系统通过VL6180X实现机械臂环境感知功能，结合多点采样与中值滤波算法（连续采集5次数据并取中值），有效抑制振动和光照干扰引起的噪声，测量误差优化至±1 mm。高精度距离反馈使Delta机械臂吸盘根据物体实际高度精确调整下降距离，吸取失败率从约5%降至低于1%，显著提升分拣任务的效率和成功率。

## 2.9 上位机控制

为提升机械臂系统的操作性与精度，我们设计并开发了一款基于Qt框架的上位机软件，用于简化Delta机械臂控制流程，提供高效、直观的人机交互体验。

软件界面采用QML编写，具备声明式布局和动态响应能力，实现了实时数据显示、按钮操作与系统状态反馈等功能。QML 与 C++ 的无缝集成，使软件兼具良好的用户体验与强大的后台处理能力。

上位机通过标准 UART 协议与紫光同创 PGL22G FPGA 板卡通信，支持通过按钮或坐标输入发送控制指令，如姿态调整、任务切换等。指令经 FPGA 快速解析后，机械臂可在毫秒级内响应操作请求。

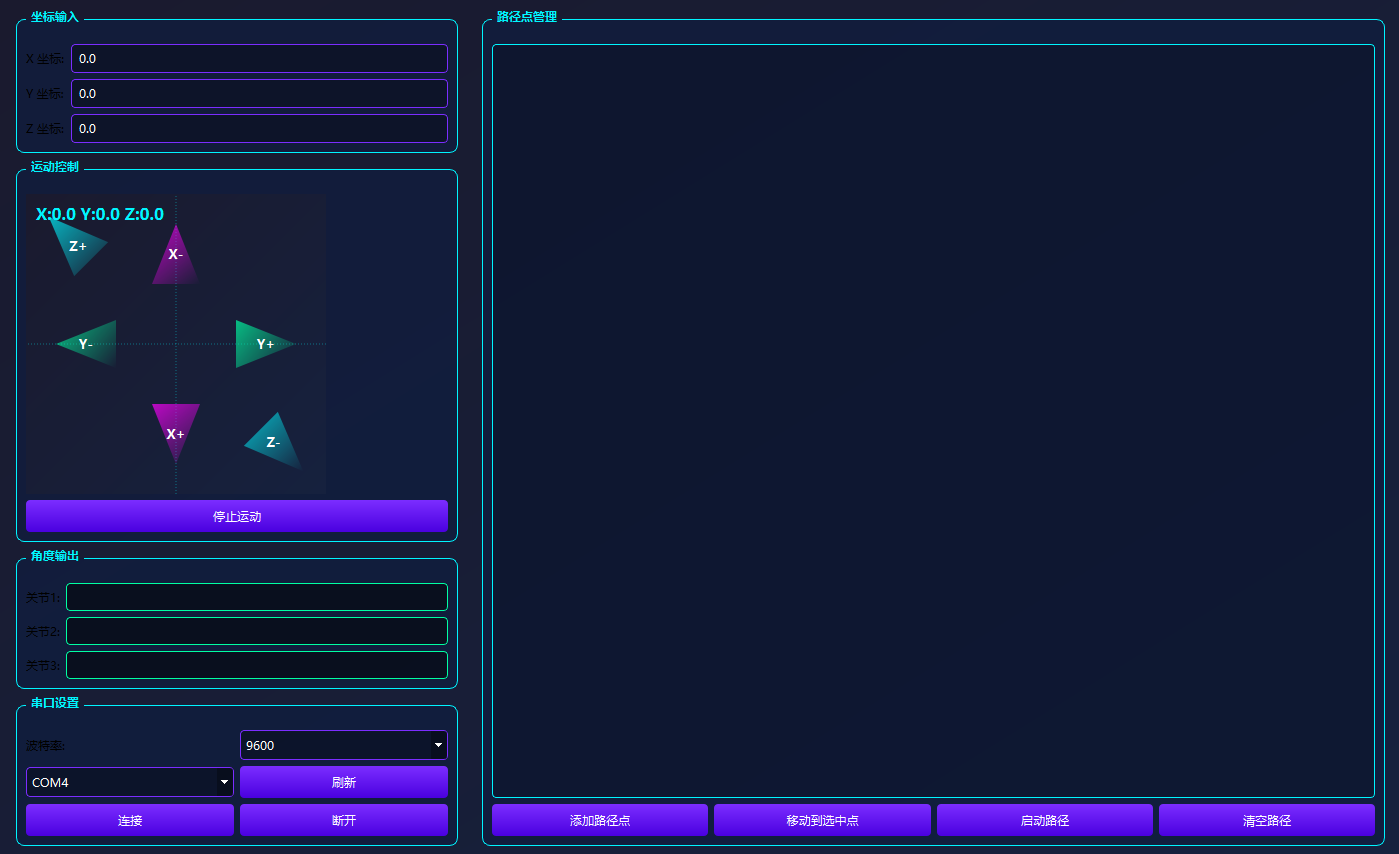
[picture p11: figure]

此外，软件支持实时显示机械臂的状态信息，包括关节角度、末端坐标、分拣进度及识别结果等，帮助操作人员全面掌握系统运行状况。借助 QML 的动态界面刷新能力与 C++ 的高效底层通信机制，该软件在复杂工业分拣场景中运行稳定，有效提升了系统操作的精度与便捷性。

图2.6 上位机界面

# 3 关键模块技术分析

## 3.1 步进电机控制模块

步进电机控制模块驱动双机械臂的步进电机，FPGA生成脉冲信号实现精准角度控制。为解决固定频率控制导致的启动与停止抖动，我们开发了梯度加减速算法，动态调整脉冲频率，确保平滑运动。

对于步进电机，其步进角度α，位置θ，速度ω 有以下公式：

α=(2π)/(spr)(rad) θ=nα(rad) ω=α/(δt)(rad/sec)

其中 spr 为每圈步数， n 是步数，δt 为脉冲间隔时间。

为实现平稳的启动和停止，需控制加速度和减速度，我们可以采用恒定加速度/减速度产生线性速度曲线，即可以得到下图：加速度、位置与时间的关系。

图3.1.1 加速度和位置与时间的关系

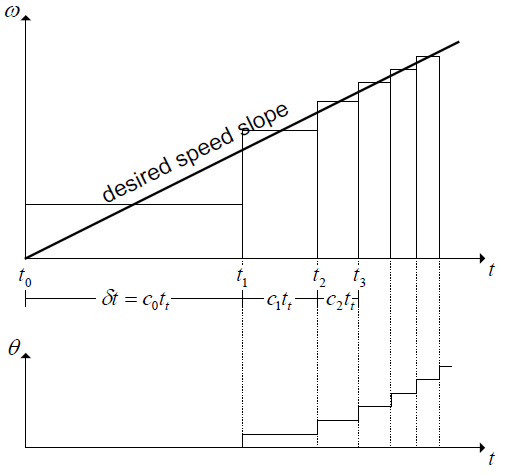
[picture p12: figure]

其中脉冲间隔时间 δt 直接影响电机速度，需根据目标速度计算，为了得期望的速度曲线，可以看到下图的对比。

图3.1.2 理想速度曲线与实际步进脉冲生成的速度曲线的对比

由图中，我们看到初始计数器延迟 C_0 和后续延迟 C_n 可以通过以下公式计算：

c_0 =1/(t_t)√((2α)/ω) c_n =c_0 (√(n+1)-\sartn)

但是这些计算涉及大量的浮点运算，不仅会浪费FPGA大量的资源，也会损失步进电机的精度。

为降低计算复杂度，我们提出了使用泰勒级数近似计算延迟：

c_n =c_(n-1) -(2c_(n-1))/(4n+1)

当 n = 1 时，这种近似方法引入的误差仅为0.44，与直接计算 C_0 的误差为0.876相比，精度较高且计算更简单。

以上是数学理论推导，接下来我们带入到实际Verilog代码。

在步进电机控制模块（stepper_motor_ctrl）的设计中，系统通过50MHz系统时钟驱动步进电机，以实现基于输入目标角度的精确旋转方向、速度和位置控制，并确保运动过程中的平滑加速、匀速和减速。为了提升控制精度，输入角度被放大256倍，通过放大倍数保留更多浮点数据以减少量化误差。

模块内定义了步进电机的关键参数，以适配不同机械臂的应用场景：Delta机械臂：脉冲周期范围为5000至10000，对应50MHz时钟下约5kHz至10kHz的步进频率。平行四边形机械臂：脉冲周期范围为6000至1000，对应50MHz时钟下约6kHz至1kHz的步进频率。 针对不同轴的电机，设置了独立的加减速参数，以优化机械臂末端的运动稳定性。

为简化数学推导中涉及的复杂计算（如平方根运算），模块引入了加速步长机制，即每隔一个脉冲后调整脉冲周期。运动过程被划分为三个阶段：加速阶段：脉冲周期从最大MAX_PULSE_PERIOD逐步减小至最小值MIN_PULSE_PERIOD，实现速度递增；匀速阶段：脉冲周期保持在MIN_PULSE_PERIOD，以维持最高速度运行；减速阶段：脉冲周期从MIN_PULSE_PERIOD逐步增大至MAX_PULSE_PERIOD，实现速度平滑下降。

其中加速和减速步数根据总步数动态分配：若总步数小于两倍加减速步数，则加速和减速各占一半，无匀速阶段，否则，加速和减速步数固定，剩余步数为匀速阶段。

在ModelSim仿真中得到如下波形图：

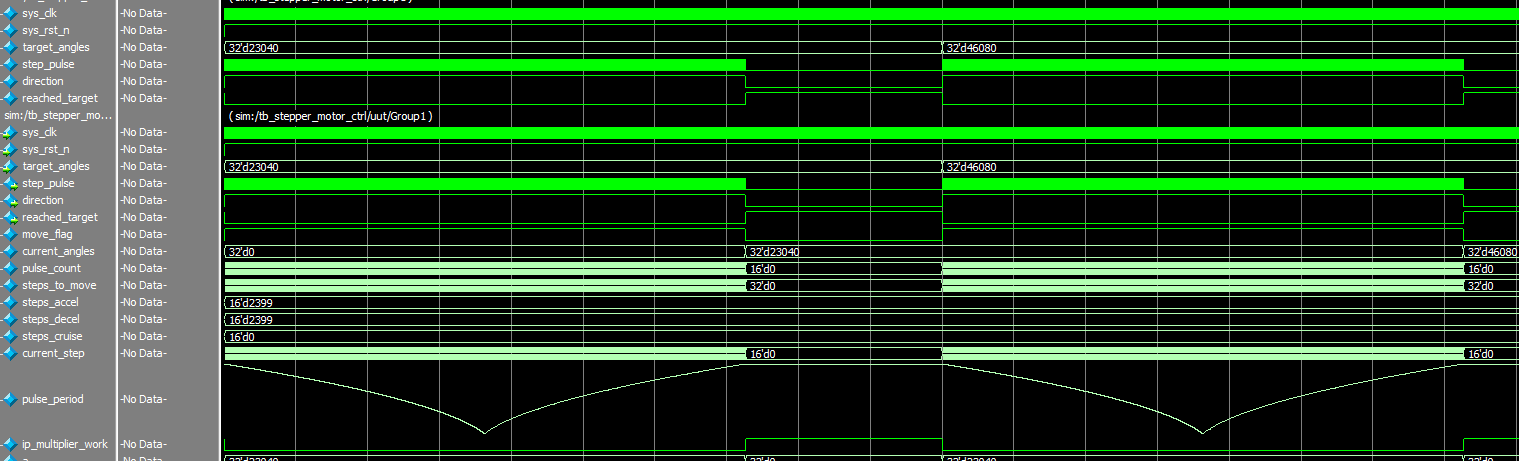
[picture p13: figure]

图3.1.3 步进电机梯度加减速仿真波形

在图3.1.3中可以看到，控制步进电机的脉冲周期逐渐减小（速度变快）之后再逐渐增大（速度减小），由于仿真总步数小于两倍加减速步数，故波形中没有体现匀速运动部分。

## 3.2 Delta机械臂控制

### 3.2.1 Delta机械臂设计

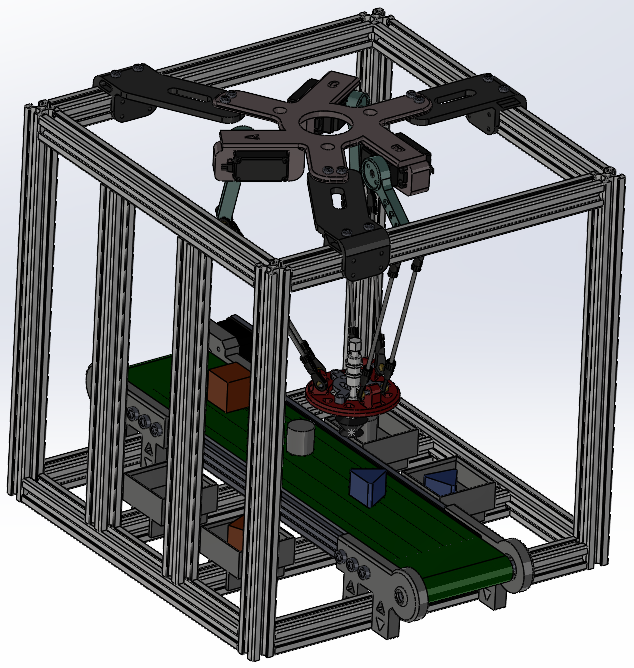
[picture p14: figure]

Delta机械臂是一种高性能的并联机器人，采用轻量化结构和并联设计，减少了运动部件的惯性，其中电机和驱动单元通常安装在固定基座上，移动部分仅包括末端执行器和连接杆，降低了整体惯性，提高了能效和响应速度。其设计特点使其在工业自动化领域中表现出色，特别适用于需要快速、精确操作的场景。
出于经济性和稳定性，我们使用SolidWorks自主设计并打印Delta机械臂。

图3.2.1 Delta机械臂模型

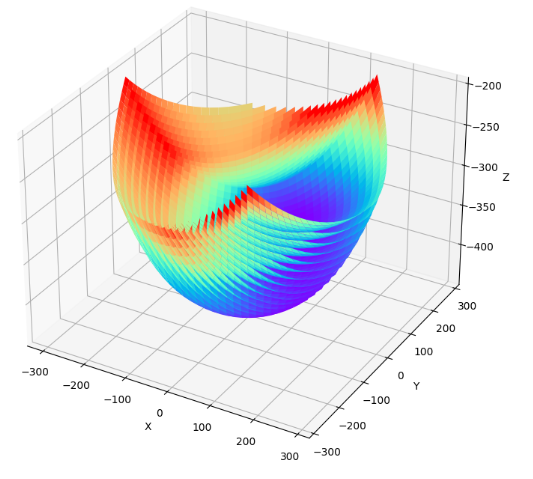
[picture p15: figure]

在机械臂设计中，我们定义了Delta机械臂相关的参数：主动臂长130mm，从动臂长316mm，静平台半径74.69mm，动平台半径34.64mm。之后便可计算机械臂的工作空间，其代表了机器人的活动范围，是衡量机器人工作能力的一个重要指标。机器人的工作空间定义为：在结构限制下末端执行器能够到达的所有位置的集合。

图3.2.2 Delta机械臂工作空间

使用python程序可以计算得到我们的机械臂工作空间为X轴和Y轴为-170mm到170mm，Z轴为-200mm到-400mm。由此，我们搭建了一个400*400*600mm的铝材框架，确保机械臂能正常工作。

### 3.2.2 Delta机械臂逆运动学解算

逆运动学解算作为Delta机械臂控制的核心技术，旨在根据已知的末端执行器在三维空间中的位置和姿态，精确计算机械臂各关节变量的过程，也被称为机器人运动学的求解。

（1）结构解析

Delta机械臂采用独特的并联机构设计，其结构由多个关键部件协同构成，具有高刚性、高速性和高精度的特点。具体构件包括：固定基座：我们采用铝材框架，将机械臂安装在铝材框架顶部。活动平台（末端执行器）：位于机械臂底部，放置吸盘以及VL6180X距离传感器。三组对称的运动链：每组运动链由一个驱动臂（主动臂）和两个平行连杆（从动臂）组成，通过球铰链或万向节连接基座和活动平台。驱动系统：使用三个步进电机，安装在固定基座上，通过运动链控制活动平台的运动。

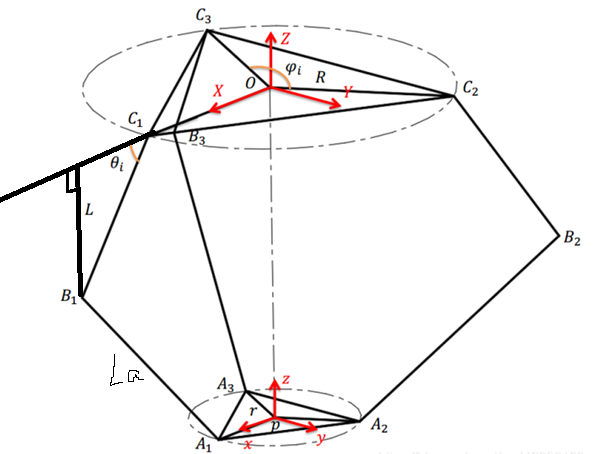
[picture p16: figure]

将主动臂和从动臂抽象成一根线，静平台与动平台抽象成三角形，那么可以得到Delta机械臂的数学模型：

图3.2.3 Delta结构数学简化模型

图中对应的参数含义如下表：

表3.2.1 机械臂模型参数

结构参数 | 数学模型参数 | 含义
|OCi| | R | 静坐标系原点O到静平台各顶点的长度
|pAi| | r | 动坐标系原点p到动平台各顶点的长度
Op | [x y z]^T | 动坐标系的原点相对于静坐标系的位置矢量
|CiBi| | L | 主动臂的长度
|BiAi| | La | 从动臂的长度
θi | θi | 主动臂与静平台夹角

（2）运动学方程分析

静坐标系与静平台的空间几何关系如图所示。

则Ci在静坐标系O-XYZ中的位置矢量为：

OCi= [RcosφiRsinφi0]

φi=(i-1)/3 π ,(i=1,2,3)

图3.2.4 静平台坐标系

同样也可以得到点Ai在动坐标系

p- X'Y'Z'中的位置矢量：

pAi= [rcosφirsinφi0]

图3.2.5 动平台坐标系 φi=(i-1)/3 π ,(i=1,2,3)

根据几何关系，可以得到点Bi在静坐标系O-XYZ中的位置矢量为：

OBi = [(R+Lcosθi)cosφi(R+Lcosθi)sinφi-Lsinθi] φi=(i-1)/3 π ,(i=1,2,3)

O p 为动坐标系的原点 p 相对于静坐标系的矢量

O p = [x y z]^T

则点Ai在静坐标系O-XYZ中的位置矢量为：

OAi=O p+p Ai = [rcosφi+xrsinφi+yz] φi=(i-1)/3 π ，(i=1,2,3)

因此可以得到AiBi的矢量表达式为：

AiBi=OBi-OAi= [(R+Lcosθi-r)cosφi-x(R+Lcosθi-r)sinφi-y-Lsinθi-z]

最后，根据AiBi= La，可推导出运动学方程：

{, f(θ)=(R+Lcosθi-r), , [f(θ)cosφi-x]^2 + [f(θ)sinφi-y]^2 = La^2

（3）逆运动学解算

得到运动学方程之后，便可进行反解。

已知机械臂末端的空间坐标（X，Y，Z），需要求解每一个电机的角度。

即（ θ_1 ， θ_2 ， θ_3 ），其中 φi=(2i-2)/3 π ，( i =1,2,3)。

[(R+Lcosθi-r)cosφi-x] ^2 +

[(R+Lcosθi-r)sinφi-y]^2 + [-Lsinθi-z] ^2 = La ^2 ①

1、将 φ1=0，φ2=2/3π， φ3=4/3π 分别代入①式得：

[(R+Lcosθ_1 -r)-x] ^2 + y^2 +（Lsinθ_1 +z）^2 = La ^2 ②

[-1/2(R+Lcosθ_2 -r)-x] ^2 +

[(√3)/2(R+Lcosθ_2 -r)-y]^2 +（Lsinθ_2 +z）^2 = La ^2 ③

[-1/2(R+Lcosθ_3 -r)-x] ^2 +

[-(√3)/2(R+Lcosθ_3 -r)-y]^2 +（Lsinθ_3 +z）^2 = La ^2 ④

2、将x，y，z代入②③④式中，并化简，得：

A1=2L(r-R+x)

B1 = - 2 z L

C1=(r-R+x)^2 +y^2 +z^2 +L^2 –La^2

A2=2L(r-R-0.5x+0.8660y)

B2 = - 2 z L

C2=(r-R-0.5x+0.8660y)^2 +(0.8660x+0.5y)^2 +z^2 +L^2 –La^2

A3=2*(r-R-0.5*x-0.8660*y)*m

B3 = -2 * z * m

C3=(r-R-0.5x-0.8660y)^2 +(0.8660x-0.5y)^2 +z^2 +L^2 –La^2

3、以上是对空间坐标（X，Y，Z）的预处理，得到结果之后，有一个通式如下：

Asinθ + Bcosθ = C

对于这个通式的通解为：

tanθ=(-AB-C√(A^2 +B^2 -C^2))/(A^2 -C^2)

最后使用 arctanθ 即可求出每一个电机的角度值。

### 3.2.3 Delta机械臂逆运动学Verilog实现

在Verilog代码的实现中，Delta机械臂的逆运动学解算被划分为三个功能模块，以实现空间坐标到电机角度的精确转换。

逆运动学解算的实现首先从pretreat_data模块开始，该模块负责对输入的空间坐标（X, Y, Z）进行预处理，遵循逆运动学推导的第二步（如文档3.2.2所述）。为提升定点运算的精度并避免有效数据的丢失，输入的X、Y、Z坐标被放大16倍，而输出的中间参数（称为ABC参数）进一步放大65536倍（即2^16）。若不进行这种倍数放大，定点运算的精度限制将导致计算过程中显著的有效数据丢失，从而影响解算结果的准确性。基于推导的数学公式，pretreat_data模块将原始坐标代入抽象表达式进行计算。例如，原始公式为：

C1=(x+r-R)^2 +y^2 +z^2 +m^2 -n^2

在放大65536倍后，公式转换为：

C1=(16x-10253)^2 +(16y)^2 +(16z)^2 –5436604416

这种放大数据的处理方式不仅有效避免了精度损失，还简化了复杂表达式的计算过程，使其更适合Verilog的定点运算和硬件实现。放大后的数据通过移位操作实现，进一步提升了计算效率，同时增强了模块的模块化程度，为后续计算单元提供了高质量的输入。

calculate_angle模块实现了逆运动学解算的第三步推导，专注于计算每个驱动电机的目标旋转角度。该模块基于推导得到的通式，集成了多种计算单元以完成复杂的数学运算：首先，乘法器单元用于处理坐标的平方和加减运算，确保快速完成公式中的多项式计算；其次，开平方器单元专门负责计算涉及距离的平方根操作，例如上述公式中的中间变量计算；最后，CORDIC算法模块通过坐标旋转数字计算机算法高效实现角度的迭代计算，输出精确的电机角度。CORDIC算法采用串行计算方式，显著优化了硬件资源的利用率，同时保证了计算的实时性。经测试，该模块能够在14个时钟周期内完成一次角度计算。

motion_solver模块作为逆运动学解算的顶层模块，采用三段式有限状态机（FSM）设计，负责协调pretreat_data和calculate_angle模块的执行流程，确保整个解算过程的有序性和高效性。三段式FSM依次调用预处理和角度计算模块，并将最终输出的角度数据传输至步进电机控制模块，从而完成完整的逆运动学解算。

## 3.3 平行四边形连杆机械臂控制

### 3.3.1 机械臂的设计

平行四边形连杆机械臂是一种基于平行四边形机构的机械结构，与Delta机械臂相同，广泛应用于工业机器人和自动化设备中，其设计特点使其在运动稳定性和负载能力方面具有独特优势。

同样，此机械臂我们也使用SolidWorks自主设计并打印平行四边形连杆机械臂控制。

图3.3.1 机械臂尺寸草图

在机械臂的设计上，本系统采用了平行四边形连杆机构的四轴结构，这一设计通过独特的几何特性显著简化了逆运动学解算过程，同时确保机械臂末端执行器在运动过程中能够维持固定的姿态。

然而，传统的平行四边形连杆机械臂在执行物品托盘的拿取和放置任务时，其运动范围受限于机械结构的固有约束，难以满足分拣场景中对较大工作区域的需求。为此，我们在传统三轴结构的基础上，特意为机械臂的Y轴增加了一根平移轴，通过引入额外的步进电机实现了四轴控制。Y轴运动范围为-300毫米至700毫米，提供了充足的纵向移动能力以应对托盘在传送带上的不同位置；X轴运动范围为-300毫米至300毫米，支持机械臂在水平方向上的灵活移动；Z轴运动范围为-100毫米至270毫米，确保末端执行器在垂直方向上能够完成从托盘拾取到放置的全程操作。

### 3.3.2 机械臂逆运动学解算

对机械臂的位置逆解算法的实现，可以使用D-H法、几何法进行分析求解。其中几何解析法，根据连杆型码垛机械臂现有的几何关系进行分析，并建立方程求解。在图3.3.2、图3.3.3所示的坐标系链中，以第0坐标系的视角为基准，以平行于地面作XOY，垂直于地面并穿过O点作Z轴。

图3.3.2 右视图坐标系链 图3.3.3 左视图坐标系链

此时假设底座步进电机S0初始位置为指向+X轴；大臂步进电机S1的初始位置为指向+Z轴；小臂步进电机S2初始位置为指向机械臂末端的反向。

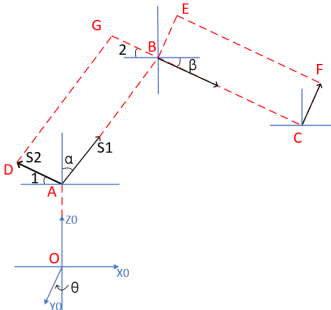
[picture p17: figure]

则有如下图3.3.4、图3.3.5所示。

图3.3.4 右视图几何分析模型 图3.3.5 左视图几何分析模型

∠ θ 为S0偏转角，∠ α 为S1偏转角，∠1为S2偏转角

由机械臂构型中，以左视图3.3.5中，ABDG和BCEF构成两个平行四边形，以其几何特性，可以得到：∠2=∠ β ，∠1=∠2；

在图3.3.4中，两个平行四边形ABIH、BCFE随着大臂的角度变化而变化，而机械臂的末端执行器由于平衡三角(EBI)的长度、内角皆恒定而保持水平。

综合下来，采取几何解析法，只需求取的角为：∠ θ 、∠α、∠β。

图3.3.6 机械臂的模型简化

图3.3.6是几何解析法的思想对机械臂的模型简化。

这里，我们设定：已知C点坐标（x，y，z）,AB为大臂长度L1，BC为小臂长度L2，到这里，我们需要求解三个量：

1.转台转动的角度（记为步进电机S0角度）

2.大臂转动的角度（记为步进电机S1角度）

3.小臂转动的角度（记为步进电机S2角度）

图3.3.7 俯视图 图3.3.8 平面投影

（a）以机械臂俯视图看，如图3.3.7，AB、BC分别为大臂和小臂的平面投影，θ则为转台转动的角度，此时有关系式：

由此可得转台角度 θ ，

（b） 以机械臂侧视图看，如图3.3.8，将大臂AB、小臂BC投影于机械臂所在的平面，可得出需求解大臂角 α 、小臂角 β 。

图3.3.9 CC1>OA 图3.3.10 CC1=OA

图3.3.11 CC1>OA 图3.3.12 CC1<OA

首先求解大臂角 α ：

如图3.3.9，做一条垂直于Z轴的线CC1与X轴相交于C1点，做一条平行于X轴，与A点重合的线AA1，相交CC1于A1点。

；

由C点坐标可得，

大臂AB、小臂BC已知，

余弦定理求解 ∠AOB :

其中 OA = L1,AB = L2,OA=d1

此时有3种情况，

1 当CC1>OA时，有图3.3.9所示，
2 当CC1 = OA时，则有图3.3.10所示，

此时，AA1与CA重合，

3 当CC1<OA时，有图3.3.12所示，

其次求解小臂角β：

依如图3.3.11，做一条平行于Z轴的线CC1与X轴相交于C1点，做一条平行于X轴，与A点重合的线AA1，相交CC1于A1点，同时过B点做平行线可得到角β。

此时可得，

由余弦定理得，

其中，在求解大臂角α时，已得∠CAA1,∠BAC，故

### 3.3.3 机械臂逆运动学Verilog实现

在平行四边形连杆机械臂的Verilog实现中，其逆运动学解算相比Delta机械臂更为复杂，涉及的运算量显著增加，计算过程也更为繁琐，主要由于其四轴结构（包括大臂、小臂、旋转轴及Y轴平移轴）需要同时满足多关节耦合关系和运动范围约束。为提升模块化设计水平、优化硬件资源利用率并保证计算的实时性，整个逆运动学解算过程被划分为三个子模块：solver_big_and_small_arm、solver_rotation 和 arm_motion_solver。

solver_big_and_small_arm模块负责对输入的空间坐标（X, Y）进行计算，其中输入的X是真实的X坐标与Y坐标的平方和开根号的结果，而输入的Y则是真实的Z坐标值。这一模块的核心任务是计算机械臂大臂角和小臂角的数值。大臂角定义为大臂与X轴负半轴之间的夹角，顺时针方向为正；小臂角则为大臂与小臂之间的夹角，逆时针方向为正。基于文档3.2.2的数学推导，设计将复杂的逆运动学公式抽象化，使其更适合Verilog的定点运算和硬件实现。与Delta机械臂类似，该模块集成了多种计算单元，包括乘法器用于处理坐标的平方和运算、开平方器用于计算距离的平方根，以及CORDIC算法模块用于高效迭代计算角度。此外，为应对平行四边形连杆机械臂更复杂的几何关系，模块新增了一个32位宽的有符号数除法器，该除法器仅需16个时钟周期便可完成一次除法运算。

solver_rotation模块负责处理输入的空间坐标（X, Y），其中X为真实的X坐标，Y为真实的Y坐标，其主要任务是利用CORDIC算法模块高效计算旋转轴电机的目标旋转角度。由于平行四边形连杆机械臂紧贴Delta机械臂的铝材框架运行，存在潜在的碰撞风险，为此模块在角度计算后增加了额外的旋转方向约束。根据计算得到的旋转角度，系统明确规定了顺时针或逆时针的旋转方向，确保机械臂在运动过程中能够避开铝材框架的物理障碍。这一方向约束有效提升了系统在狭窄空间内的安全性，同时保持了运动轨迹的精确性。

arm_motion_solver作为逆运动学解算的顶层模块，采用了三段式有限状态机（FSM）设计，通过状态机协调solver_big_and_small_arm和solver_rotation模块的执行流程。该FSM设计分为初始化状态、计算状态和输出状态三个阶段，分别负责模块初始化、角度计算以及数据传输至步进电机控制模块。FSM通过时序管理实现了大臂、小臂和旋转轴三个轴电机角度的同步解算，最大限度减少了计算延迟，并确保了机械臂各关节的协调运动。

## 3.4 机械臂路径规划

### 3.4.1 Delta机械臂线性插补算法

路径规划旨在为Delta机械臂末端执行器生成从起始点到目标点的运动轨迹，满足速度、加速度、避障和机械约束要求。Delta机械臂的运动学特性要求路径规划综合考虑三维平移自由度和几何约束。其工作空间呈圆锥形，受驱动臂、连杆长度及关节角度范围限制，增加了规划复杂性。此外，机械臂的高速运动特性要求路径具备平滑的加速度和减速度曲线，以避免振动和失步。

路径规划以逆运动学解算（参考文档3.2）为基础，将目标位置转化为电机角度序列，并引入时间维度生成连续运动轨迹。常见方法包括直线插补和样条曲线插补。样条曲线插补通过构造三次样条曲线，提供连续的速度和加速度曲线，适合复杂轨迹规划，但其高计算复杂度对FPGA的APM资源消耗较大，尤其在逆运动学解算已占用大量资源的情况下。直线插补则通过在笛卡尔空间线性划分路径点，确保末端执行器沿直线移动，适用于简单点到点运动，避免复杂浮点运算，显著降低资源占用。

为适配紫光同创PGL22G FPGA的有限资源，系统选用直线插补算法。算法将路径分为等距段（通常为64段，优化移位操作），通过整数运算替代浮点运算，确保计算高效且精度满足要求。规划过程同步调整各轴步进长度，匹配最大轴差值，保障轨迹平滑性。测试表明，该方案有效抑制运动抖动，末端执行器定位误差控制在±1mm以内，满足高速分拣任务的平滑性和稳定性要求。

图3.4.1 未加算法的机械臂末端运动轨迹

在实际实现中，Delta机械臂的路径规划结合硬件控制和软件算法，旨在生成平滑、精准的末端执行器运动轨迹，满足速度、加速度和机械约束要求。路径规划模块与步进电机控制模块协作，通过逆运动学解算和动态脉冲周期调整，实现平滑点到点运动。

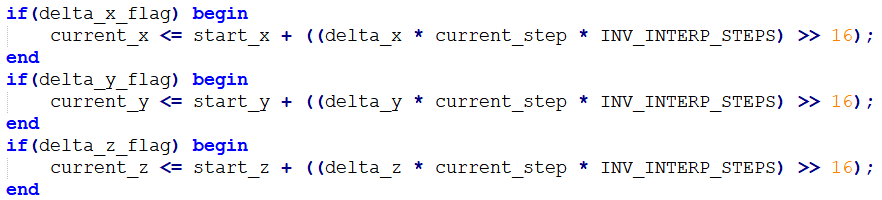
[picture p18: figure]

在基于Verilog的控制系统中，路径规划模块将目标路径分解为离散采样点，通过逆运动学解算模块计算每个采样点对应的电机角度。以Delta机械臂为例，其步进电机脉冲周期范围为5000至10000（对应50MHz时钟下5kHz至10kHz频率）。为确保平滑运动，模块预计算加速度和减速度阶段的步数：加速阶段脉冲周期从最大值渐减至最小值，匀速阶段维持最小值，减速阶段渐增至最大值。此策略避免速度突变，显著提升末端执行器稳定性。

图3.4.2 线性插补Verilog代码

在Verilog实现中，路径规划采用64细分直线插补策略，将目标位置（X, Y, Z）与当前位置的差值分为64等份，生成中间坐标点。通过定点数乘法和移位操作实现线性插值，避免复杂浮点运算，适配紫光同创PGL22G FPGA的资源限制。中间坐标点逐一输入逆运动学解算模块，计算电机角度，并由步进电机控制模块驱动运动。

为避免细分带来的精度丢失，设计对差值小于64的坐标点跳过插补，直接驱动至目标点。同时，最后一个执行点强制设为目标坐标，消除累计误差。相比未插补的直接运动，64细分策略确保末端执行器沿直线轨迹移动，减少轨迹偏差和机械振动。

相比未使用插补的直接运动方式，线性直线插补确保了机械臂末端沿点到点的直线轨迹运动，减少了轨迹偏差和机械振动。这种方法在笛卡尔空间中通过线性划分路径点，确保了轨迹的几何一致性，同时结合脉冲周期的动态调整，实现了速度和加速度的平滑过渡。结果表明，采用64细分直线插补后，机械臂末端的运动轨迹更加平顺，特别是在拾取与放置等点到点任务中，末端执行器的定位精度和稳定性均得到了显著改善。

图3.4.3 线性插补运动轨迹

### 3.4.2 Delta机械臂门型路径规划

为实现高效、安全的拾放任务，Delta机械臂采用门型轨迹从拾取点运动至放置点。门型轨迹包含三个阶段：

（1）竖直上升段，沿Z轴从拾取点上升至安全高度，避开障碍物；

（2）水平移动段，沿X-Y平面移动至放置区域上方；

（3）竖直下降段，沿Z轴下降至放置点，完成物体放置。

此轨迹通过中继点设计，有效避免与环境（如物体或框架）的碰撞。然而，门型轨迹各阶段衔接点存在方向突变，导致末端执行器在转角处经历加速度突变，引发机械振动，影响稳定性、定位精度并可能加速机械疲劳。为缓解此问题，系统结合步进电机控制中的梯度加减速算法，通过动态调整脉冲周期实现速度平滑过渡，降低振动。同时，优化运动速度以平衡效率与稳定性。

门型轨迹控制通过Verilog模块化设计实现，集成于路径规划模块中，作为顶层模块协调轨迹生成与运动执行。模块接收目标空间坐标（X, Y, Z），生成门型轨迹的坐标点序列，包括上升段安全高度点、水平段过渡点和下降段目标点。轨迹生成采用有限状态机（FSM）控制，工作流程如下：

1. 生成中继点坐标，传递至逆运动学解算模块，计算对应电机角度。
2. 步进电机控制模块驱动末端执行器运动至中继点，完成后返回到位信号。
3. FSM切换至下一状态，生成后续中继点坐标，重复上述过程，直至到达目标点，完成吸取或放置。

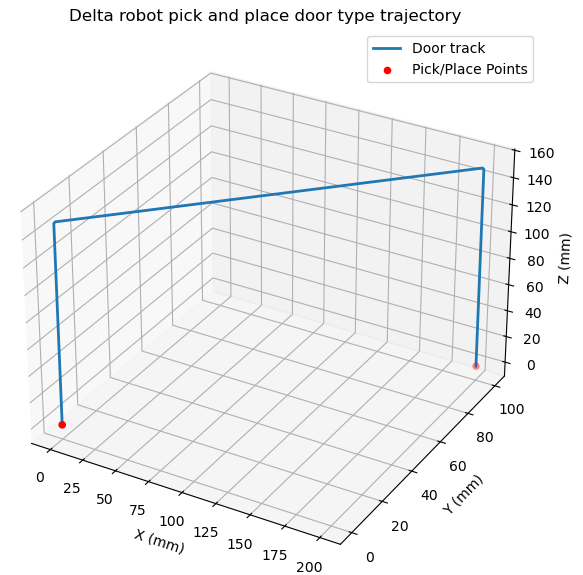
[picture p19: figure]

为提升平滑性，轨迹各阶段结合前述64细分直线插补策略，将路径点细分为64等份，通过定点数运算和移位操作生成中间坐标，确保轨迹几何一致性。测试表明，门型轨迹结合梯度加减速和64细分插补后，末端执行器定位误差控制在±1mm以内，振动显著减小，拾放任务成功率提升至90%以上。

图3.4.4 门型轨迹运动示意图

### 3.4.3 平行四边形连杆机械臂路径规划

尽管平行四边形连杆机械臂的逆运动学解算因其复杂的几何约束和多自由度特性而相对困难，其路径规划在本工程中的实现却较为简洁，设计重点在于满足特定任务需求。本项目中，平行四边形连杆机械臂的主要功能是执行托盘的拿取和放置操作，模拟工业流水线上的分拣和分装任务。其目标是实现不同类型物体的分拣与装载，服务于自动化生产线的效率提升和劳动力替代。与Delta机械臂相比，该机械臂的应用场景对末端执行器的精度和稳定性要求较低，主要关注任务的完成可靠性和操作的连续性，因此未对路径规划施加过高的实时性和复杂性要求。

考虑到紫光同创PGL22G FPGA的APM资源限制和机械臂较低的运动速度要求，本设计未在平行四边形连杆机械臂的控制中引入线性插补等高精度算法。相反，路径规划采用基于状态机的控制方法，通过定义一系列离散状态逐步管理机械臂的姿态和运动过程。具体而言，设计了26个状态，每个状态对应机械臂从起始位置到目标位置的特定姿态或动作阶段。这种状态机驱动的路径规划方法简化了计算复杂度，避免了对浮点运算和细分插补的依赖，从而降低了硬件资源消耗，适配了当前控制系统的性能限制。

通过状态机的设计，平行四边形连杆机械臂能够实现姿态的连续控制，从而确保运动过程的精确性和可靠性。在项目中，机械臂的运动范围受限于整体铝材框架的物理约束。铝材框架位于机械臂的操作区域内，任何运动失控都可能导致碰撞事故。为此，精确的姿态控制成为避免碰撞的关键需求，考虑到机械臂需在有限的空间范围内完成托盘的拿取和放置任务，尤其是在铝材框架的狭窄区域中操作，传统路径规划方法需进一步优化以适应这一复杂环境。

图3.4.5 机械臂路径规划

为解决上述问题，本设计在机械臂控制系统中引入了旋转轴电机的方向信号机制。即旋转轴电机的控制不仅包括目标角度的计算，还明确规定了到达目标角度的旋转方向，即逆时针旋转或顺时针旋转。通过在Verilog代码中为旋转轴添加方向信号，系统能够在运动规划中动态选择最优路径。例如，当机械臂检测到铝材框架可能干扰其运动轨迹时，方向信号可触发逆时针或顺时针旋转，以绕过障碍物。这种方向选择的灵活性显著增强了机械臂在狭窄空间中的避障能力，使其能够安全、有效地完成托盘的拿取和放置任务。

状态机通过26个状态协调姿态调整和路径移动，每个状态对应特定的姿态调整或位置移动，例如下降至托盘位置、水平移动通过框架区域以及上升至放置点，结合旋转轴的方向信号，状态机在关键转折点（如通过框架时）根据实时姿态信息选择合适的旋转方向，确保机械臂末端始终保持安全距离，避免与铝材框架发生接触。此外，方向信号的引入还优化了运动效率，减少了不必要的回转动作，从而缩短了整体操作时间。

## 3.5 OV5640摄像头数据采集

### 3.5.1 摄像头图像预处理

在本项目中，为方便后续对图像处理，使用了前置的图像预处理，在预处理阶段，色彩转换的思想，将不同颜色的色块直接提取出来，从而实现将12个薄片分成4x3组需要识别的色块，在一帧截取的图片中，只有三个色块，经过二值化处理后，可以得到只含相同颜色的背景与色块图，如下图所示：

图3.5.1 HSV提取蓝色H分量 图3.5.2 蓝色分量二值化

图3.5.3 HSV提取黄色H分量 图3.5.4 黄色分量二值化

### 3.5.2 颜色识别与提取思路

在数字图像处理领域，RGB色彩空间是广泛使用的颜色表示方法，其通过Red（红色）、Green（绿色）和Blue（蓝色）三个分量来定义颜色，每个分量的取值范围在理论上为[0%, 100%]，反映了颜色的相对强度。然而，在计算机系统中，大多数基于RGB色彩空间的程序采用1字节（8位）来存储每个分量，此时每个分量的取值范围转换为我们常见的[0, 255]，本文后续部分也将沿用这一取值范围。

这种表示方式直观且便于硬件实现，但其固有缺陷在于无法有效区分颜色属性中的色度、亮度和饱和度等信息。在本项目中，视觉识别模块需要精确提取物体的颜色特征（红、蓝、黄、绿），而RGB色彩空间由于其分量耦合性，在处理不同色度时存在困难，因此引入了HSV色彩空间模型以克服这一局限。

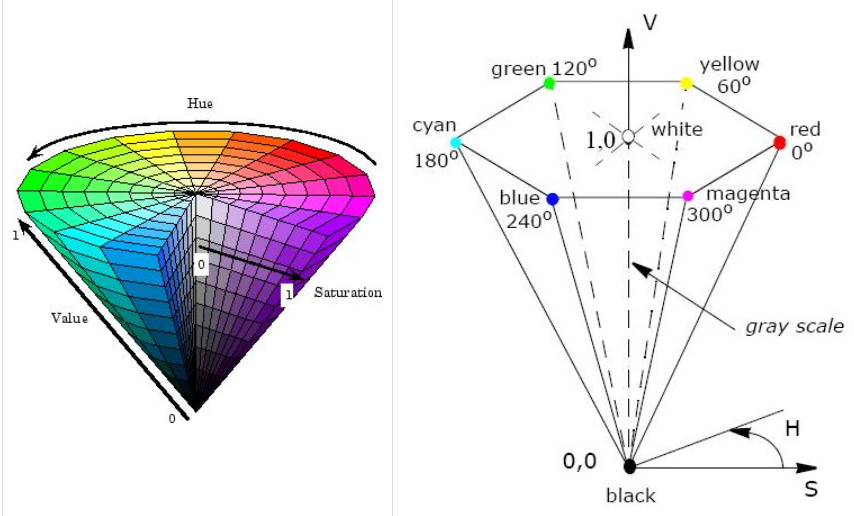
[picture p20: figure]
hsv模型

HSV（Hue, Saturation, Value）色彩空间由A. R. Smith于1978年提出，基于颜色的直观特性构建，也被称为六角锥体模型（Hexcone Model）。在HSV模型中，颜色由三个独立参数共同定义：色度（Hue, H）表示颜色的种类，通常以0°至360°的圆形角度表示；饱和度（Saturation, S）表示颜色的纯度，范围为[0, 1]，数值越大颜色越鲜艳；明度（Value, V）表示颜色的亮度，同样范围为[0, 1]，数值越大颜色越亮。相较于RGB模型，HSV空间更符合人类视觉感知，能够直观地分离色度、饱和度和亮度信息，为颜色识别提供了便捷的处理基础。图3.5.5展示了HSV色彩空间模型的几何表示：

图3.5.5 HSV色彩空间模型

在本项目中，HSV模型的引入主要利用色度（H）分量来区分不同的颜色。通过预设特定的色度阈值范围，例如红色的H值范围约为0°至30°和330°至360°、蓝色的H值范围约为180°至240°、黄色的H值范围约为30°至90°、绿色的H值范围约为90°至150°，系统能够有效分离目标物体的颜色特征。为实现颜色转换和提取，设计首先将OV5640摄像头采集的RGB565图像数据转换为HSV空间，随后通过修改H分量实现颜色变换。例如，将红色的H值（0°-30°或330°-360°）和黄色的H值（30°-90°）调整至蓝色的H值范围（180°-240°），再将修改后的HSV数据转换回RGB格式。

如下是通过颜色H值改变达到改变物体颜色的目的，如下：

图3.5.6 20元本色、通过改变H值后的20元、50元对比图

### 3.5.3 Verilog实现

颜色识别模块是系统视觉处理的核心，负责从RGB565图像中提取目标颜色色块，简化后续物体形状（圆形、正方形、六边形）和位置识别。相较于RGB色彩空间，HSV模型通过色度（H）、饱和度（S）和明度（V）分离颜色特征，适合颜色提取。HSV将颜色映射到0°-360°色度区间，如红色（0°-30°，330°-360°）、黄色（30°-90°）、蓝色（180°-240°）、绿色（90°-180°），便于精准区分。

该模块通过将RGB565图像转换为HSV空间，并调整色度（H）分量，将目标颜色（红、黄、绿）统一映射到蓝色区间（180°-240°），从而简化颜色提取。例如，黄色（30°-90°）通过增加约150°色度，红色（0°-30°，330°-360°）增加约180°色度，均映射至蓝色区间。转换后的图像再转回RGB空间，通过提取蓝色分量实现颜色分离。这一方法显著降低了颜色识别的复杂度，为形状识别提供清晰输入。

为提升模块的灵活性和复用性，设计了三个参数接口：SELECT_BIT、ADD_VALUE和THRESHOLD。SELECT_BIT选择灰度通道；ADD_VALUE控制色度增量（如150用于黄色转蓝色，180用于红色转蓝色）；THRESHOLD设置二值化阈值（如100，适配工业环境噪声）。例如，配置SELECT_BIT=2、ADD_VALUE=150、THRESHOLD=100可高效提取黄色物体。这种参数化设计使模块通过简单配置即可适应多种颜色识别需求。

模块核心逻辑依赖于色度调整和阈值切换机制，确保在复杂光照条件下实现准确颜色提取。结合HSV转换、色度操控和二值化处理，模块实现鲁棒的色块分离，为后续形状和位置识别提供高质量输入。

对于ADD_VALUE参数，其取值来源于对色彩的直方图统计，通过颜色统计直方图或者颜色行波形状图，寻找颜色分布的区间，从而确定颜色转换时的阈值，以人民币的颜色H值统计直方图为例，如下：

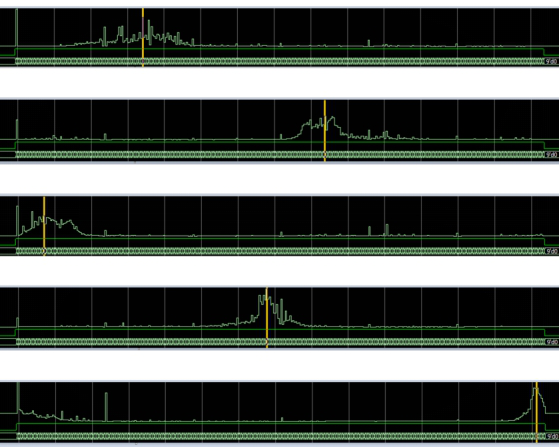
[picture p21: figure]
人民币颜色H分布

图3.5.7 人民币颜色H分布

在颜色识别模块中，目标颜色的提取依赖于不同颜色在HSV色彩空间中的直方图分布特性。通过分析波形特点，可以发现不同颜色在H分量上的分布范围存在显著差异，一旦确定了目标颜色的分布范围，便可通过设置特定的阈值参数实现颜色的精确分离。

利用ModelSim仿真工具对图像数据对应行的通道波形进行分析。观察目标区域的颜色通道波形，可以直观地确定颜色分布的阈值范围。图3.5.8展示了HSV转化后二值化阈值参数确定的仿真结果。该图呈现目标区域内不同颜色通道的分布特性，其中横轴表示图像行像素点，纵轴表示H值或灰度值的大小，波形峰值和谷值反映颜色的分布区间。

图3.5.8 确定二值化阈值

## 3.6 物体形状识别

物体形状识别是本系统视觉处理模块的重要环节，旨在从OV5640双目摄像头采集的720P分辨率二值化图像中精确识别托盘内12个随机摆放物体的形状（圆形、正方形、六边形），为机械臂的分拣任务提供关键数据支持。原始的图片是一副包含12个色块的图片，通过合适的灰度二值化阈值设置，可以得到如下图片：

图3.6.1 二值化图 图3.6.2 Sobel边缘检测图

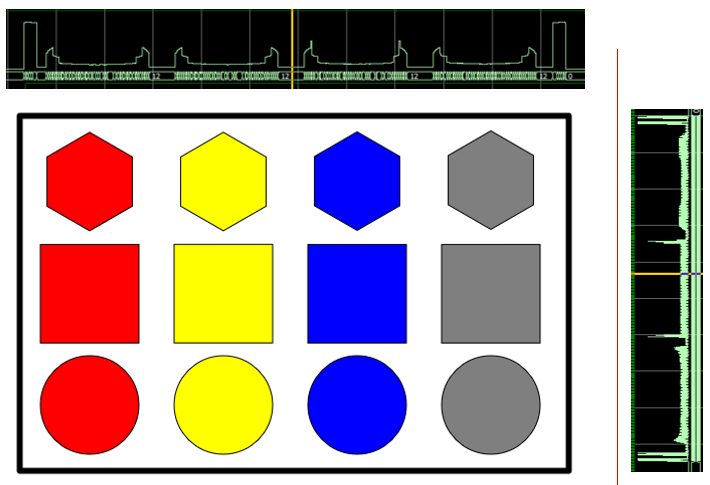
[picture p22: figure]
水平竖直投影示意

可以看出，此时的二值化图片中，包括边框在内的12个图片全部呈现白色，在RGB8的像素数值上表现为黑色0，白色255，二值化处理后表现为黑色0，白色1，这样我们就得到了一副由0和1组成的图片，或者说是一个二维数组，现在只需要分析这个二维数组的特征就可以得到有薄片和没有薄片位置的信息。现在将上面二值化的图像进行水平和竖直投影，对图片进行边缘检测。

图3.6.3 水平竖直投影示意

基于投影波形的特征分析，形状识别模块通过寻找波峰和波谷的位置，将图像分割成12个小的部分，如图3-6-4所示（见附图“图3-6-4：分割后的色块区域”）。每个分割区域的边界坐标（最左、最右、最上、最下）被提取，用于计算色块的几何中心和形状参数。

图3.6.4 托盘分割示意图

在初步分割出12个独立色块区域后，系统进一步采用垂直投影方法对每个物体的边界区域进行详细分析，以实现形状的精确识别。投影过程通过累加二值化图像中目标区域内每一列的像素值，生成相应的直方图，统计像素分布的特性。例如正方形由于其规则的垂直和水平边缘，在投影直方图中呈现较高的峰值，而圆形和六边形因边缘曲率的差异，其投影分布范围呈现不同的特征分布模式。

为进一步提升识别精度，系统结合面积计算和边界框的宽高比特征，对投影分析结果进行多维度验证。面积计算通过统计二值化区域内白色像素（值为1）的总数，辅助判断物体的整体尺寸，而边界框的宽高比则通过提取外接矩形的最左、最右、最上、最下坐标计算获得。这种多特征融合方法能够校正单一投影分析可能出现的误判。例如，正方形的宽高比接近1，表明其边界框呈正方形分布，而六边形由于其几何结构的非正交性，宽高比通常略有偏差（例如0.8至1.2之间）。通过宽高比的校正规则，系统能够更准确地分类圆形、正方形和六边形，避免因边缘噪声或投影偏差导致的错误识别。

## 3.7 VL6180X距离传感器

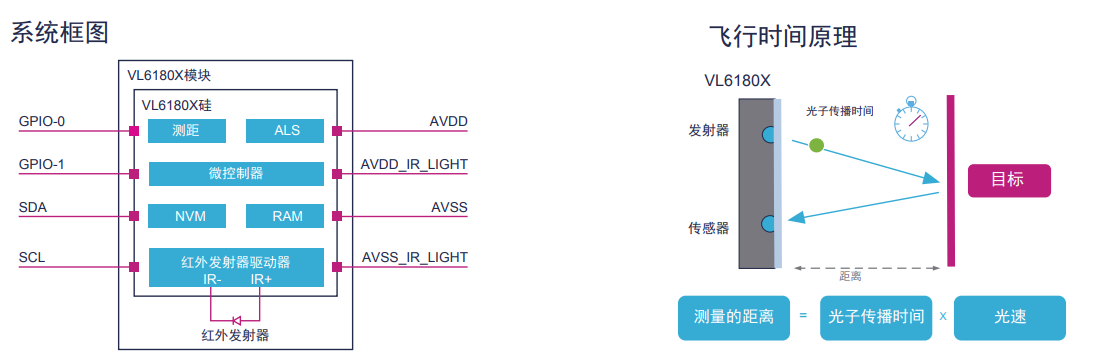
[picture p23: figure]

### 3.7.1 传感器介绍

图3.7.1 传感器介绍

VL6180X是一种高性能时间飞行（Time-of-Flight, ToF）测距传感器，集成了测距传感器，能够以1毫米的分辨率测量0至10厘米的距离。该传感器在较小测距范围内表现出较高的精度，非常适合安装在Delta机械臂末端，用于检测末端吸盘与托盘上物体之间的距离。

在本设计中，VL6180X与紫光同创PGL22G板卡通过自编写的软核I²C接口实现通信，旨在配置传感器工作模式并实时采集距离数据。设计过程分为以下几个关键步骤：首先，开发软核I²C模块，利用Verilog语言实现主设备（FPGA）与从设备（VL6180X）的通信协议。模块包括状态机控制、数据发送/接收逻辑及时钟生成单元，确保I²C信号的准确同步。初始化阶段，按照传感器数据手册建议的序列，通过写入特定寄存器配置VL6180X为单次测距模式，启用红外激光发射并设置采样间隔。

### 3.7.2 软核I2C原理

图3.7.2 数据有效时序图

I2C只有两条线，一条数据线SDA，一条时钟线SCL。SDA线上的数据在时钟的高电平周期内必须稳定，数据线的高电平或低电平状态只能在SCL线上的时钟信号为低电平时才能改变，每传输一个数据位都会产生一个脉冲。

图3.7.3 开始和停止时序图

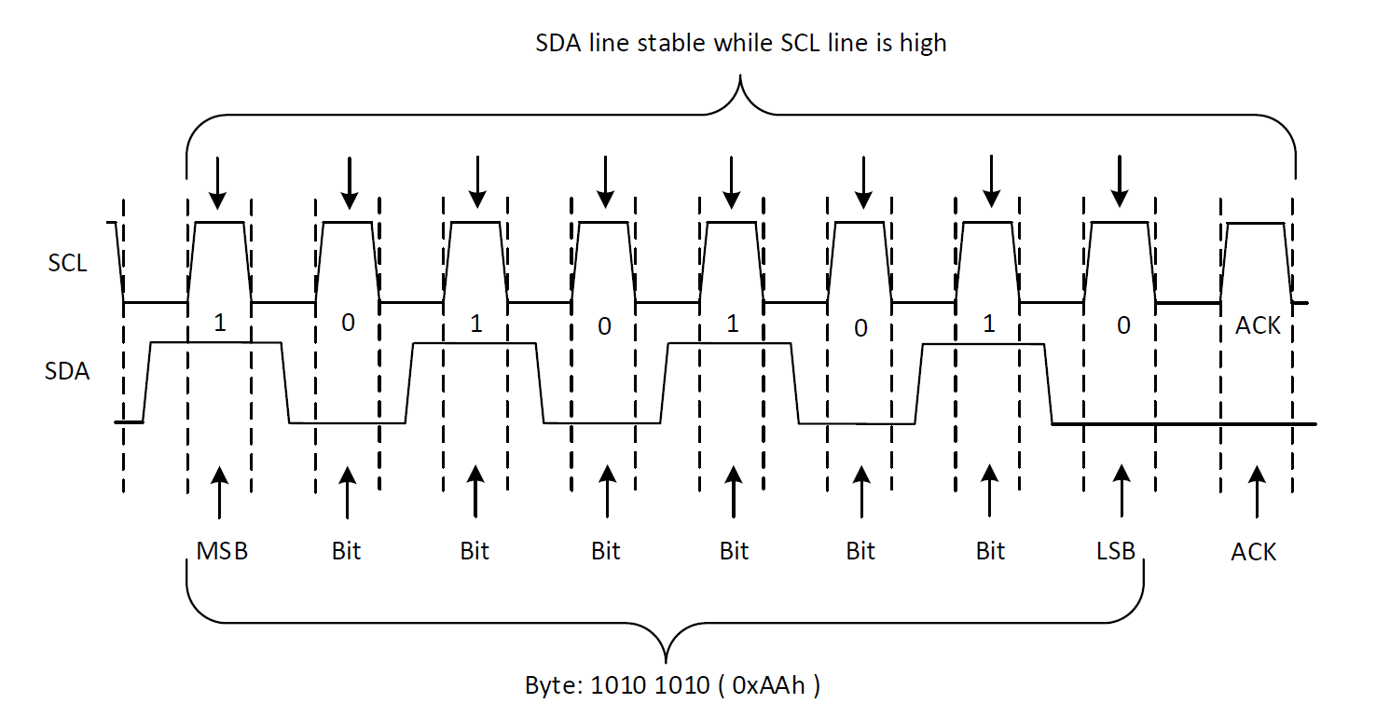
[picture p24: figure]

当 SDA由高电平转为低电平，并且SCL为高电平时，为开始条件 。 SDA由低电平转为高电平，并且SCL为高电平时，为结束条件。

图3.7.4 数据传输过程时序图

在SCL的每个时钟脉冲期间传输一个数据位。一个字节由 SDA 线上的八个bit组成。一个字节的地址可以传输的数据是设备地址、寄存器地址或从从机写入或读取的数据。

首先以最高有效位 （MSB） 传输数据。在 START 和 STOP 条件之间，可以将任意数量的字节数据从主设备传输到从设备。SDA线路上的数据在时钟周期的高电平阶段必须保持稳定，因为SCL高电平时数据线的变化被解释为控制命令。

图3.7.5 ACK应答和NACK不应达时序图

数据的每个字节（包括地址字节）后跟来自接收器的一个 ACK 位。ACK 位允许接收器与发送器通信该字节已成功接收并且可以发送另一个字节。发送应答时，ACK=0（因为都接上拉电阻，因此若ACK设置为1时，无法判别是否进行了应答操作）。在接收器可以发送 ACK 之前，发射器必须释放 SDA 线路。要发送ACK位，接收器应在ACK/NACK相关时钟周期（周期9）的低电平阶段拉下SDA线，以使SDA线在ACK/NACK相关时钟周期的高电平期间稳定为低电平。

### 2.7.3 软核I2C设计

本设计的I²C通信协议实现参考了正点原子的例程，并结合与VL6180X传感器通信的具体需求进行了针对性优化，以确保通信的正确性、稳定性和高效性。设计中定义了以下关键通信参数：VL6180X传感器的默认I²C设备地址为7位二进制值0101001；FPGA的系统时钟频率（SYS_CLK_FREQ）设定为50 MHz；SCL时钟频率（SCL_FREQ）配置为250 kHz。

在代码实现上，软核I²C模块采用了一个包含16个状态的有限状态机设计，全面覆盖I²C通信协议的各个阶段。这些状态包括空闲（IDLE）、起始信号1（START_1）、发送设备地址（SEND_D_ADDR）、应答检测1（ACK_1）、起始信号2（START_2）、发送读地址（SEND_RD_ADDR）、读取数据（RD_DATA）、非应答信号（N_ACK）和停止信号（STOP）等。

写操作流程包括：通过 SEND_D_ADDR 状态发送设备地址，随后在 SEND_B_ADDR_H 和 SEND_B_ADDR_L 状态分别发送 16 位寄存器地址的高字节和低字节，紧接着通过 WR_DATA 状态发送数据，并在 ACK_x 状态检测从设备的应答信号。

读操作流程则涉及 START_2 和 SEND_RD_ADDR 状态以重新发送设备地址（切换至读模式），通过 RD_DATA 状态读取数据，在 N_ACK 状态发送非应答信号，并最终在 STOP 状态完成通信。

状态切换由计数器cnt_i2c_clk（控制SCL时钟周期）和cnt_bit（管理数据位传输）精确控制，i2c_end信号在STOP状态置高，标志着一轮I²C通信的结束。这一设计通过FSM的精细管理，确保了通信过程的可靠性和时序准确性。

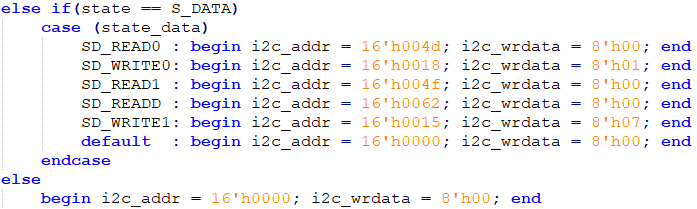
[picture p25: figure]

### 3.7.4 传感器寄存器配置

图3.7.6 传感器寄存器数据采集

基于前述的i2c_ctrl软核，设计开发了vl6180x模块，专门负责VL6180X传感器的初始化配置和实时数据采集功能，为Delta机械臂的高精度定位提供支持。

顶层状态机（state）包含两个状态：初始化状态（S_INIT）和数据采集状态（S_DATA）。在S_DATA状态下，定义6个子状态（state_data）：读取状态寄存器（SD_READ0）、启动测量（SD_WRITE0）、检查测量完成（SD_READ1）、读取距离数据（SD_READD）、清除中断（SD_WRITE1）和等待（SD_WAIT），覆盖测距任务完整流程。

在初始化阶段，vl6180x模块通过计数器init_cnt执行39次I²C写操作（INIT_NUM=6'd39），配置VL6180X寄存器，遵循数据手册推荐流程。例如，写入0x0207=0x01启用测距功能，0x0208=0x01设置默认工作模式，并优化0x00e3至0x0014等寄存器，初始化过程确保传感器稳定运行。

数据采集阶段，模块在S_DATA状态下循环执行以下流程：读取0x004d确认传感器状态；写入0x0018=0x01启动单次测量；读取0x004f（检查位2）确认测量完成；从0x0062读取8位距离值（单位毫米）；写入0x0015=0x07清除中断。为控制测量间隔，模块使用计数器WAIT_COUNT=16'd100000（50 MHz时钟，约50 ms）实现SD_WAIT状态等待。

## 3.8 HDMI显示

HDMI（High-Definition Multimedia Interface）作为音视频设备互联的标准，依托TMDS（Transition Minimized Differential Signaling）技术实现高速、可靠的数据传输。本节阐述HDMI硬件设计与视频时序标准的实现。

### 3.8.1 HDMI硬件

本设计基于开发板HDMI接口，采用四对TMDS差分信号通道：一对传输时钟信号，三对负责数据传输。HDMI传输原理与DVI一致，均依赖TMDS技术。在发送端，HDMI接口接收24位并行RGB数据（每像素R、G、B各8位），经编码和并/串转换后分配至三个数据通道，同步时钟信号通过专用通道发送。接收端对串行信号解码并进行串/并转换，恢复为并行数据，结合时钟信号实现精准同步后送至显示控制单元。

TMDS编码是高效传输的核心。每个数据通道将8位视频或音频数据编码为10位序列，通过异或/异或非逻辑运算生成前8位，第9位指示运算方式，第10位确保直流平衡。此编码机制优化传输最小化和抗干扰能力，支持视频数据（8位）、控制数据（2位）或数据包（4位，含音频和纠错码等）。HDMI传输分为三个阶段：视频数据周期（传输像素数据）、控制数据周期（传输同步信号等）和数据岛周期（传输音频和附加信息），满足多样化传输需求。

### 3.8.2 视频时序标准

HDMI显示采用逐行扫描，从屏幕左上角逐点由左至右扫描，完成一行后通过消隐信号抑制电子束，返回下一行起点。行同步信号确保每行扫描同步。一帧扫描完成所有行后，场同步信号触发扫描返回左上角，进行场消隐，开始下一帧。一行扫描的持续时间称为水平扫描时间，其倒数为行频率；一帧扫描的持续时间称为垂直扫描时间，其倒数为场频率（即屏幕刷新率），常见值为 60 Hz、75 Hz 等。本设计采用标准的 60 Hz 场频率。

3.8.1 行同步时序

### 3.8.3 HDMI输出程序设计

HDMI输出模块在本项目中负责处理双目摄像头采集的视频流，并将其高效传输至外部HDMI显示设备，以实现实时视频监控和识别结果的可视化。为满足工业场景中对低延迟和高稳定性的要求，系统采用了一系列数据处理与存储机制，确保视频流的连续性和一致性。双目摄像头采集的720P分辨率RGB565格式视频数据首先存储至写FIFO（First-In-First-Out）缓冲区，FIFO的深度和宽度根据数据吞吐量设计，缓冲区能够暂时缓存摄像头输出的突发数据，防止因数据采集速率与处理速率不匹配导致的丢帧问题。随后的数据处理通过生成DDR3的Burst写请求，将FIFO中的数据写入DDR3存储器，Burst模式的连续读写操作优化了内存带宽利用率，提升了数据传输效率。

读取过程与写入过程类似，当读FIFO中的数据量低于预设阈值时，系统触发DDR3的Burst读请求，从存储器中提取视频数据以供HDMI控制器处理。DDR3作为中间存储介质，提供了足够的容量和带宽，支持双路视频流的并行处理。为实现双目摄像头的同步显示，设计中实例化了两个frame_read_write模块，分别负责管理左目和右目视频数据的存储与读取操作。每路视频数据在DDR3中的存储地址被分配为独立区域，通过地址偏移量避免数据冲突，确保高效访问和数据完整性。左目数据用于显示二值化后的处理结果，右目数据则叠加识别后的物体画框标注，两种画面通过HDMI控制器在显示屏上划分为左右两部分，实时呈现。

3.8.2 第一路视频存储地址

3.8.3 第二路视频存储地址

图3.8.4 实现逻辑框图

HDMI输出显示模块通过三个核心模块实现视频数据的处理与传输，结构如图3.8.4所示，确保双目摄像头采集的720P RGB565视频流实时输出至显示设备。vidio_pll模块生成稳定的时钟信号，为视频传输和TMDS编码提供精确时序基准。基于1024×768@59.94 Hz时序设计（参考3.8.2），vidio_pll利用锁相环技术将FPGA 50 MHz系统时钟调整至约65 MHz点时钟频率，保证信号同步与稳定传输。dvi_encoder模块负责将VGA格式视频信号转换为符合HDMI 1.4协议的DVI信号，完成TMDS差分编码和数据封装。视频流处理模块作为核心数据处理单元，从DDR3存储器读取双目摄像头720P RGB565视频数据，并整合图像处理算法的输出。整合后的视频流经dvi_encoder处理，通过HDMI接口输出，实现双路视频的实时显示。

图3.8.5 HDMI显示画面

为实现双路视频的同步显示，设计中调用了两个video_rect_read_data模块，将显示屏幕划分为左右两部分，分别呈现来自双目摄像头的画面。左边显示左边摄像头的画面，数据经由图像处理的算法，显示二值化之后的画面；右边显示右边摄像头的画面，在原始画面上对识别的物体画框。

直观的双画面呈现显著提升了人机交互体验，为操作人员提供实时监控和调试支持。

## 3.9 上位机交互

上位机系统采用模块化设计，基于Qt框架构建，包含输入模块、计算模块、通信模块和显示模块。输入模块负责接收用户输入的三维坐标或关节角度数据；计算模块实现运动学正逆解算法，完成坐标与角度的转换；通信模块通过串口与Delta机械臂硬件交互；显示模块负责实时可视化运动轨迹和状态信息。界面采用深色调设计，配以蓝色边框和紫色按钮，增强用户体验。

### 3.9.1 上位机界面

图3.9.1 上位机界面

（1） 串口设置

在上位机界面的左下角，设计了一个简洁且功能齐全的串口设置区域，作为用户与机械臂控制系统交互的核心入口。这一区域通过直观的布局和高效的操作方式，为操作人员提供了与紫光同创PGL22G FPGA板卡通信的便捷手段。

设计中，串口设置区域支持串口波特率的调节和串口接口的选择，用户可以通过下拉菜单轻松选择目标串口，例如常见的COM4，并根据需求调整波特率至115200 bps，匹配FPGA通信模块的默认设置。这种灵活的配置选项确保了上位机与硬件之间的兼容性，适应不同的硬件环境和通信需求。

（2）坐标输入

在上位机界面的左上角是用户输入机械臂末端的空间坐标点的入口，可分别设置x、y、z的坐标，用于直观的展示。当输入 x、y、z 坐标值后，上位机内部会有Delta机械臂的运动学逆解算法，能够实时输出对应的三个关节角度值，让机械臂的运动控制更为直观高效。角度输出的 UI 界面如图 3-3 所示：

图3.9.2 坐标输入与坐标输出

（3）交互控制

系统设计了直观的3D交互控制界面，支持多种操作方式以满足用户对机械臂运动的灵活控制需求。界面提供6个方向按键，分别控制X、Y、Z坐标的正负方向调整，用户可通过点击进行微调，或长按实现快速调整，操作便捷高效。界面的右侧为大型可视化窗口，实时展示机械臂的三维运动轨迹和坐标点，增强用户对运动状态的直观感知。交互控制功能包括以下核心操作：

添加路径点：用户在坐标输入框中输入目标位置的X、Y、Z值后，点击“添加路径点”按钮，系统会将该坐标点保存至路径点管理列表，并实时显示已添加的路径点数量（如“5个路径点”），便于用户查看和管理。

移动至指定路径点：用户可在路径点管理列表中选中某一目标点，点击“移至选中点”按钮，系统通过串口将该点坐标发送至下位机，驱动机械臂自动运动至目标位置。

自动执行路径：点击“启动路径”按钮，系统按顺序读取路径点管理列表中的所有坐标，依次发送至下位机，机械臂将按照预设路径依次运动，实现自动化轨迹控制。

清空路径点：当需要重新规划路径时，用户可点击“清空路径”按钮，一键清除路径点管理列表中的所有数据，确保新路径规划的准确性。该功能通过直观的路径点管理界面，支持单点定位和连续轨迹控制，为用户提供了灵活高效的机械臂运动路径调整方式。

### 3.9.2 功能实现

（1）基本的串口通信

串口通信通过C++后端逻辑与QML前端界面的协同实现，确保高效、稳定。C++后端利用Qt的QSerialPort库，通过串口管理类封装串口初始化、参数配置（波特率9600）、状态管理及数据收发功能。借助Qt信号与槽机制，实时监控串口状态（如连接或断开）及接收数据，触发相应槽函数更新状态或处理数据，确保通信可靠性。

QML前端提供直观操作界面，包含“打开串口”“关闭串口”“刷新串口”等按钮，通过与C++后端的交互实现操作。串口配置（如波特率、端口）经QML传递至后端，支持动态调整。QML与C++交互基于上下文属性和信号与槽机制，串口管理类作为上下文属性暴露给QML，控件可直接调用后端方法（如发送数据）。后端状态变化或接收数据通过信号传递至QML，槽函数实时更新界面状态显示框，便于用户监控。

（2）指令发送

指令发送功能是上位机与Delta机械臂交互的核心环节。系统通过串口将用户输入的坐标或路径点数据转换为控制指令，并发送至下位机驱动机械臂运动。

在C++后端，指令发送基于QSerialPort的数据写入功能实现。系统首先将用户输入的坐标数据（X、Y、Z）通过运动学逆解算法转换为关节角度值，然后按照预定义的通信协议将角度值封装为指令数据包。指令数据包包含起始位、数据位、校验位和结束位，确保数据传输的完整性。串口管理类调用QSerialPort的write()方法将数据包发送至下位机，同时通过read()方法接收下位机的反馈数据，验证指令是否成功执行。

在路径点自动执行模式下，系统会按顺序遍历路径点管理列表中的坐标点，逐一转换为指令并发送至下位机。为避免指令发送过于频繁导致机械臂运动不稳定，系统设计了时间间隔控制机制，确保每次指令发送后等待机械臂完成当前动作，再发送下一指令。

在QML前端，用户通过“启动路径”按钮触发指令发送流程。界面会实时显示当前执行的路径点序号和机械臂状态，增强用户对执行过程的感知。若通信过程中发生错误（如串口断开或数据校验失败），系统会通过界面弹窗提示用户，并暂停指令发送，待用户重新连接串口后恢复操作。

# 4 性能指标分析

## 4.1 机械臂运动控制

机械臂运动控制是本系统性能的核心组成部分，其性能直接决定了分拣任务的成功率和效率。

步进电机的稳定性提供了对整套系统提供了强有力的支持，配合我们开发的梯度加减速算法，使稳定性得到进一步的提升。在整套系统中，Delta机械臂使用了3个步进电机，平行四边形连杆机械臂使用了4个步进电机，我们对每一个电机的加速加速度、减速加速度、最大速度、最小速度都做了对应的适配。

具体参数如下表，此参数对应的芯片是紫光PGL22G，主频50MHz。

表4.1 步进电机参数

步进电机序号 | 最大速度脉冲频率 | 最小速度脉冲频率 | 加速/减速加速度
连杆机械臂平移轴 | 3000 | 6000 | 10
连杆机械臂旋转轴 | 2000 | 8000 | 1
连杆机械臂大臂轴 | 3000 | 8000 | 2
连杆机械臂小臂轴 | 3000 | 8000 | 2
Delta机械臂 | 5000 | 10000 | 100

### 4.1.1 Delta机械臂性能

Delta机械臂作为本系统的主要执行单元，通过门型路径规划实现了从拾取点到放置点的精准移载操作，其运动精度在测试中达到了±1毫米的水平，满足工业分拣任务的基本要求。结合前述优化的步进电机控制参数，每次拾取与放置操作的平均耗时约为2秒。然而，由于Delta机械臂的步进电机减速比仅为1:3，且其结构件采用3D打印材料，整体强度有限，导致机械臂的运动速度受到显著限制，无法实现更高速的操作。这种速度瓶颈主要源于机械结构和驱动系统的设计特性。

在尝试提高步进电机脉冲频率以提升速度时，Delta机械臂的结构特性带来了新的挑战。由于其并联机构的设计，末端执行器的速度会随着驱动臂运动的加速而成倍放大。当运动方向发生突变（例如门型路径中上升段与水平段的衔接处）时，末端因惯性作用会产生一定的误差位移，导致定位精度的下降。此外，步进电机的减速通过同步带实现1:3的减速比，尽管系统中加入了弹簧对同步带进行张紧以减少松弛，但当运动速度进一步提高时，同步带仍会出现打滑现象。这种打滑不仅加剧了误差位移，还显著降低了机械臂末端的重复定位精度。测试表明，在高速运动下，末端定位误差可达±5毫米以上，远超分拣任务的精度要求。

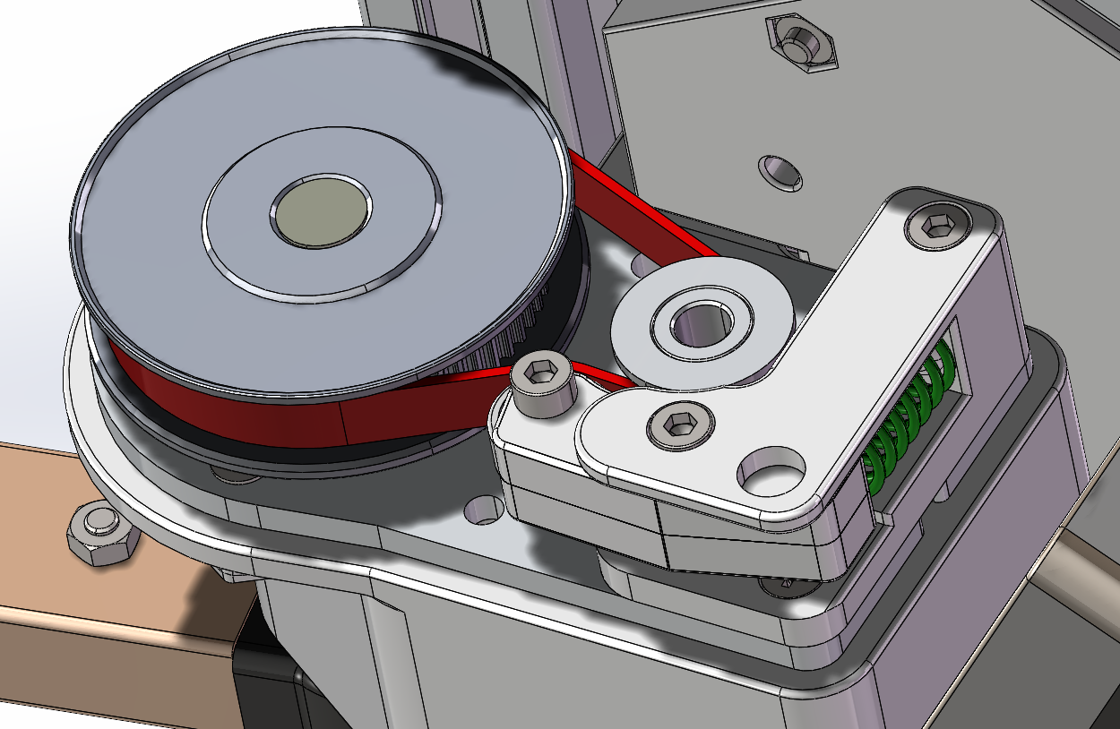
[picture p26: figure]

图4.1.1 Delta机械臂减速结构

在4.1.1图中，红色的是2GT同步带，绿色的是皮带紧张弹簧，小齿轮有20齿连接步进电机，大齿轮有60齿连接主动臂，通过皮带实现1:3的减速比。

为解决上述问题，我们通过多次实验优化了步进电机的运行参数，最终在保证重复定位精度的前提下，确定了最优速度设置。表4-1列出了经过反复测试得出的参数配置。在该参数配置下，机械臂能够在±1毫米的定位精度范围内稳定运行，同时将拾取与放置的单次操作耗时控制在2秒左右。这一速度虽然无法进一步提升，但通过梯度加减速算法和路径规划优化，显著减少了末端振动和同步带打滑现象，为系统的整体稳定性和可靠性提供了保障。

在系统的协同操作中，Delta机械臂和平行四边形连杆机械臂的分工明确且高效。Delta机械臂负责从托盘中拾取物体并按颜色分类放置，每完成三次拾取与放置操作后，系统会触发平行四边形连杆机械臂的运动，开始执行托盘的拿取和更换任务。与此同时，Delta机械臂利用这一时间窗口执行复位操作，通过限位开关将机械臂精确地归位至零点状态。这一复位机制通过硬件限位检测，确保机械臂回到初始位置，从而有效消除因多次操作而累积的定位误差。测试表明，复位操作耗时约1秒，配合限位开关的精度（±0.2毫米），能够将累计误差清零，使Delta机械臂在下一轮拾取任务中恢复至±1毫米的定位精度。这种协同设计不仅优化了机械臂的工作节奏，还显著提升了系统在长时间运行中的稳定性和可靠性，为分拣任务的连续性提供了保障。

图4.1.2 Delta机械臂复位操作代码

### 4.1.2 平行四边形连杆机械臂性能

相较于Delta机械臂的高精度要求，平行四边形连杆机械臂在本系统中主要承担搬运和放置托盘的任务，其精度需求相对较低。托盘的拿取和放置采用磁吸方式，与Delta机械臂吸取物体的操作相比，磁吸机制显著简化了抓取和释放的复杂度，使得连杆机械臂在执行任务时更易于实现稳定的拿起与放下操作。磁吸方式通过两个电磁铁的通断控制实现，吸力可达6牛顿以上，足以应对托盘的重量（约200克），同时避免了机械夹爪可能出现的夹持不稳问题。

基于任务特点，我们在连杆机械臂上并未引入过多的复杂算法，仅保留了步进电机梯度加减速算法和逆运动学解算模块，以满足基本的运动控制需求。步进电机梯度加减速算法通过动态调整脉冲频率，确保机械臂在启动和停止阶段的平滑过渡，减少因速度突变引发的振动，单次托盘搬运耗时约为4秒，定位误差控制在±2毫米以内。尽管连杆机械臂的精度要求较低，但其扩展的Y轴运动范围（-300毫米至700毫米）通过平移轴步进电机的引入得以实现，显著提升了机械臂的操作灵活性，确保其能够适应传送带上不同位置的托盘搬运需求。整体设计在简化算法复杂度的同时，依然满足了系统对托盘搬运任务的稳定性与效率要求。

### 4.1.3 逆运动学解算

逆运动学解算是本系统核心模块，扮演着承上启下的关键角色，其主要功能是将目标坐标转换为机械臂各关节的电机角度，确保Delta机械臂和平行四边形连杆机械臂的末端执行器能够精确到达预定位置。这一模块的计算精度和速度直接影响系统的整体性能，尤其在高速连续运动场景中，逆运动学解算的速度成为影响机械臂响应时间的重要因素。为评估其性能，我们利用ModelSim仿真工具对逆运动学解算模块进行了详细测试和优化。

（1）解算精度

为确保在FPGA中进行逆运动学解算时不因定点运算而丢失精度，设计中对数据进行了多级放大处理。以Delta机械臂为例，输入的空间坐标（X, Y, Z）在进入逆运动学解算模块前被直接放大16倍，以提高运算的初始精度。随后，在数据预处理模块pretreat_data中，中间计算参数被进一步放大65536倍，以满足复杂公式对精度的需求。在角度计算模块calculate_angle中，输出的电机角度值也被放大256倍。最终，步进电机控制模块接收这一放大了256倍的角度值，并在生成脉冲数时通过右移8位还原为真实角度数据。所有放大倍数均设计为2的次方形式，使FPGA能够通过高效的移位操作完成放大与还原，极大节省了紫光同创PGL22G板卡的运算资源，同时避免了浮点运算带来的硬件开销。

为验证FPGA实现的逆运动学解算精度，我们将Verilog编写的逆运动学解算模块与Python实现的浮点运算版本进行了对比分析。


图4.1.3 ModelSim仿真Delta机械臂逆运动学解算

图4.1.4 Python逆解结果

为进一步验证Verilog实现的逆运动学解算模块的精度，我们针对Delta机械臂输入一组特定坐标（0, 0, -3800）进行了测试，其中输入坐标已放大16倍。在FPGA的Verilog实现中，角度计算结果如图4.1.3所示，输出值为6682，该值对应于放大256倍后的电机角度值。还原为真实角度后，计算为6682 ÷ 256 = 26.1015625°。相比之下，Python实现的浮点运算程序计算得到的结果如图4.1.4所示，放大256倍后的值为6680.77，真实角度为26.09677734375°。

对比两者还原后的真实角度值，差距约为0.0048°。可以看出，Verilog编写的逆运动学解算代码在紫光同创PGL22G FPGA平台上的精度极高。进一步分析，0.0048°的角度误差折算到Delta机械臂末端执行器的位置误差约为0.02毫米，远低于系统要求的±1毫米定位精度。

（2）解算速度

通过ModelSim仿真工具对解算模块进行了详细测试，分析了各子模块的时钟周期消耗和整体解算速度。图4.1.5展示了Delta机械臂逆运动学解算的仿真波形，在50 MHz的主频下，完整解算过程耗时235个时钟周期，大约4.7微秒。

图4.1.5 Delta机械臂仿真解算过程


图4.1.6展示了pretreat_data子模块的仿真波形。对输入坐标进行预处理，需完成10个乘法运算。由于板卡资源有限，模块仅使用一个乘法器IP核，通过分时复用技术降低资源占用。分时复用过程消耗20个时钟周期，整个模块总共耗时23个时钟周期。虽然分时复用牺牲了部分速度，但显著减少了DSP资源需求，为其他模块的并行计算腾出了空间。

图4.1.6 pretreat_data模块仿真波形图

图4.1.7展示了calculate_angle子模块的仿真波形。该模块负责计算电机角度，单次角度计算耗时70个时钟周期，约1.4微秒。具体耗时分布为：乘法器分时复用消耗10个时钟周期，用于处理平方和加减运算；64位宽数据的开方运算消耗34个时钟周期，采用迭代算法实现；CORDIC算法用于角度迭代计算，消耗17个时钟周期，优化了三角函数运算的资源占用。calculate_angle模块的高效实现得益于FPGA的流水线设计，总耗时约为210个时钟周期，与顶层模块的协调共同构成了235个时钟周期的整体耗时。

图4.1.7 calculate_angle模块仿真波形图

### 4.1.4 逆运动学解算资源优化

在开发过程中，紫光同创PGL22G芯片的硬件资源限制成为设计的关键挑战。该芯片仅配备30个APM，用于支持乘法等算术运算。初期在编写逆运动学解算模块时，未能充分考虑乘法器的资源消耗问题，设计中每个乘法操作均使用了32位宽的乘法器，而每个32位乘法器需消耗4个APM。两套逆运动学解算模块（Delta机械臂和平行四边形连杆机械臂）中，子模块如pretreat_data和calculate_angle分别需要5至10个乘法器，导致第一版代码总共消耗了123个APM。这一资源占用量远超芯片能力，在PDS工具中无法完成布局布线，严重阻碍了项目的实现。

为解决这一问题，我们引入了乘法器的分时复用策略。由于调用IP核使用APM的32位乘法器在单时钟周期内即可完成一次计算。以pretreat_data模块为例，最初使用10个乘法器处理坐标的平方和运算，通过分时复用技术，仅需一个乘法器即可完成所有乘法操作。分时复用通过状态机和计数器管理，依次执行10次乘法，额外增加了20个时钟周期的延迟。在50 MHz主频下，20个时钟周期耗时仅400ns，对于机械臂控制的实时性要求而言，这一延迟可以忽略不计，同时大幅降低了资源消耗。


通过乘法器分时复用的优化，最终资源配置为：Delta机械臂逆运动学解算模块使用两个32位乘法器，总计消耗8个APM；平行四边形连杆机械臂逆运动学解算模块同样使用两个32位乘法器，消耗8个APM。两套模块的总资源占用降至16个APM，远低于PGL22G芯片的30个APM上限。这种资源优化使两个机械臂的逆运动学解算模块能够集成于同一块紫光同创PGL22G板卡上，充分利用硬件资源，同时保持解算精度（误差小于0.01°）和速度（约4.7微秒）。

图4.1.8 资源消耗报告图

根据上图所示，紫光同创PGL22G FPGA板卡在实现双机械臂逆运动学解算模块等功能后，资源利用率呈现出较高的占用状态。报告显示，APM资源已全部用尽，这一结果源于逆运动学解算模块中乘法运算的高需求，尽管通过分时复用策略将初始的123个APM需求优化至16个，但其他模块在综合网表时也调用了一定的APM资源，用于执行简单的乘法或加法运算，以节省LUT资源的消耗。这种资源调度策略在一定程度上缓解了逻辑单元的压力。从逻辑资源的角度来看，工程整体使用了77%的逻辑单元，其中CLMA和CLMS的利用率均高达93%。

当前设计已接近PGL22G板卡的硬件极限，尽管如此，通过乘法器分时复用和模块化设计，系统依然在资源约束下实现了预期的功能，逆运动学解算速度（4.7微秒）和精度（误差0.0048°）均满足分拣任务的需求。

## 4.2 传感器数据处理

### 4.2.1 颜色与形状识别

在本项目中，所有工程项目的文件均通过ModelSim仿真工具进行了全面验证，以确保颜色与形状识别模块的准确性和实时性。图4.2.1展示了颜色与形状识别模块的仿真波形，详细记录了从阈值设置到坐标更新的完整过程。仿真结果显示，在50 MHz主频下，从给出颜色阈值到更新出单个颜色物体的坐标位置，耗时为12.6248毫秒。整个识别过程需依次处理四种颜色（红、黄、蓝、绿），总耗时约为50.5136毫秒，与理论计算值一致。

图4.2.1 识别仿真波形图

波形图中，各颜色物体的坐标更新过程清晰可见：红色波形表示黄色物体的坐标，橙色波形表示红色物体的坐标，蓝绿色波形表示蓝色物体的坐标，紫色波形表示绿色物体的坐标，而蓝色波形则为最终更新出的色块中心坐标点，色块坐标直接从蓝色波形中提取。

图下方，绿色波形表示阈值的变化，用于动态调整颜色提取范围；酒红色波形为场同步信号的上升沿和下降沿计数器，用于同步视频帧处理。识别模块基于HSV色彩空间转换和投影分析，首先通过H值调整（ADD_VALUE）和灰度通道选择（SELECT_BIT）提取目标颜色，随后利用水平和竖直投影分割色块区域，最后结合面积和宽高比特征完成形状分类（圆形、正方形、六边形）。

ModelSim仿真结果表明，锁定一组颜色的平均耗时为12.6248毫秒，完成全部四种颜色的识别总耗时为50.5136毫秒。为满足分拣任务的实时性要求，后续可通过并行处理优化或减少投影计算量，将总耗时压缩至30毫秒以内。

### 4.2.2 物体定位精度

在物体识别的精度优化过程中，由于时间原因，我们对物体定位任务进行了简化。通过将托盘划分为12个固定方格，限定物体放置于方格内，避免了随机摆放的复杂性，从而降低了定位算法的实现难度。在这种简化场景下，系统仅需完成物体的形状与颜色识别，即可确定其所在方格位置，为机械臂的分拣任务提供初步定位数据。

然而，随着测试的深入，发现物体为立体结构时，存在一定挑战。当物体不在摄像头正下方时，OV5640双目摄像头会拍摄到侧面视角，导致计算出的投影面积与实际垂直投影面积产生偏差。这种角度引起的面积失真直接影响形状分类的准确性，特别是在区分圆形、正方形和六边形时，可能导致误判。

为解决这一问题，我们通过反复的测试和ModelSim仿真，分析了不同视角下物体的投影面积特性，最终确定了三种形状的面积区别阈值。测试过程中，进行了12次随机摆放实验，统计了各形状在不同角度下的投影面积数据，并结合边界框的宽高比进行校正。

表4.2.1 物体识别准确率

次数 | 准确识别数 | 颜色错误数 | 形状错误数 | 颜色识别平均准确率 | 形状识别平均准确率 | 识别率
1 | 12 | 0 | 0 | 98.61% | 90.97% | 89.58%
2 | 12 | 0 | 0
3 | 11 | 0 | 1
4 | 10 | 0 | 2
5 | 11 | 0 | 1
6 | 11 | 0 | 1
7 | 10 | 0 | 2
8 | 9 | 1 | 2
9 | 10 | 0 | 2
10 | 11 | 0 | 1
11 | 10 | 1 | 1
12 | 12 | 0 | 0

## 4.3 人机交互接口

### 4.3.1 上位机交互

上位机交互模块作为本系统的人机交互核心，为操作人员提供了直观、高效的控制和监控界面，显著提升了Delta机械臂和平行四边形连杆机械臂的操作便捷性。该模块基于Qt框架开发，充分利用其跨平台特性和强大的图形界面支持，运行于PC端。界面设计采用QML语言，通过其声明式编程和动态布局特性，实现了美观且响应迅速的交互界面；核心功能如串口通信和数据处理则通过C++实现，确保了通信效率和底层控制的可靠性。

主界面以动态图形形式实时展示Delta机械臂的当前姿态（通过关节角度计算末端位置）和目标坐标（X, Y, Z），直观反映机械臂的工作状态。操作人员可通过界面上的输入框手动输入目标坐标，精确控制机械臂末端移动至指定位置，或者通过一键执行按钮调用预设路径（如门型轨迹），实现自动化拾取和放置操作。串口通信模块通过C++与FPGA板卡交互，支持115200 bps波特率，确保指令传输延迟低于10毫秒，满足实时控制需求。

### 4.3.2 语音模块实时交互

为进一步提升人机交互的便利性，本系统引入了语音模块，增强了操作人员的体验。语音模块在Delta机械臂开始拾取物体时，会实时播报当前抓取的物体信息，例如“抓取红色圆形物体”或“抓取蓝色六边形物体”，通过声音反馈直观地传达识别和操作状态。这一功能特别适用于需要监控多任务场景的操作人员，减少对视觉界面的依赖，从而提高了系统的实用性与人性化设计价值。

语音模块通过串口与紫光同创PGL22G FPGA板卡进行数据交流，接收从颜色与形状识别模块输出的物体分类结果（颜色和形状数据）以及机械臂的动作触发信号。FPGA将这些数据封装为串口命令（波特率115200 bps），传输至语音合成芯片，由其生成相应的语音输出。测试表明，语音模块的响应延迟约为50毫秒，略高于传统按钮操作的即时反馈（约10毫秒），主要由于串口传输和语音合成的处理开销。然而，这一延迟对实时性要求较低的监控场景影响不大，且直观性弥补了速度上的不足，显著提升了人机交互的便利性。

# 5 创新点

本作品在工业自动化领域通过结合多机器人协同控制、视觉感知与高精度定位技术，提出了一系列创新设计，显著提升了智能分拣系统的性能与应用价值。以下是项目的核心创新点，体现了其在技术实现和工程实践中的突破性贡献。

## 5.1 多机器人协同优化

本系统通过对Delta机械臂和平行四边形连杆机械臂的协同优化，显著提升了整体分拣效率和任务切换的稳定性，适应了工业流水线连续运行的场景需求。Delta机械臂负责物体的拾取与分类放置，每完成三次拾取后执行复位操作，利用限位开关精确回归零点状态，有效消除因多次操作导致的累计误差。与此同时，平行四边形连杆机械臂通过磁吸方式搬运托盘，电磁铁吸力达6牛顿，单次搬运耗时约5秒，定位误差控制在±2毫米，扩展的Y轴运动范围（-300至700毫米）确保了托盘在传送带上的灵活取放。

## 5.2 多级数据放大优化FPGA定点运算精度

为克服FPGA定点运算的精度限制，本设计引入了多级数据放大策略。以Delta机械臂逆运动学解算为例，输入坐标放大16倍，中间参数放大65536倍，输出角度放大256倍，所有倍数采用2的次方形式，便于通过移位操作高效实现。这一创新不仅避免了浮点运算的高资源消耗，还通过ModelSim仿真验证，Verilog实现的解算精度与Python浮点计算误差仅0.0048°，折算末端误差小于0.1毫米，远超±1毫米的系统要求。这一方法在资源受限的紫光同创PGL22G芯片（仅30个APM）上实现了高精度计算，提供了可推广的定点运算优化方案。

## 5.3 乘法器分时复用降低资源占用

针对PGL22G芯片APM资源的瓶颈，项目创新性地采用了乘法器分时复用技术。初期设计因使用32位乘法器（每个消耗4个APM）导致资源超限，通过优化仅使用两个乘法器（共8个APM）处理Delta和连杆机械臂的逆运动学解算，资源占用降至16个APM，成功通过PDS布局布线。分时复用虽增加20个时钟周期延迟，但对4.7微秒的总解算时间影响可忽略，同时将逻辑资源利用率控制在77%，实现了单板集成双机械臂控制的突破，显著提升了硬件效率。

## 5.4 逆运动学解算速度的创新优化

本作品通过在紫光同创PGL22G FPGA平台上实现逆运动学解算模块，充分利用FPGA的高并行处理能力和模块化设计，相较于传统MCU方案实现了显著的性能提升。传统MCU方案（如基于STM32的C语言实现）受限于其串行计算方式和主频（一般为100-200 MHz），单次逆运动学解算耗时通常在50-100微秒之间。在Delta机械臂和连杆机械臂的高速连续分拣任务中，这种速度难以满足亚微秒级的实时性要求，特别是在需要频繁计算电机角度以响应动态路径规划时，延迟成为瓶颈。

通过Verilog实现的逆运动学解算模块，利用FPGA的流水线设计和并行计算能力，将解算速度大幅提升至4.7微秒（235个时钟周期，50 MHz主频），比传统MCU方案快10倍以上。

## 5.5 双目摄像头分区显示与实时监控

HDMI输出模块通过创新设计，利用两个video_rect_read_data模块将1024×768显示屏划分为左右两部分，同步呈现双目摄像头的数据。左半部分显示二值化处理结果（如边缘检测后的色块轮廓），右半部分叠加识别画框（标注颜色和形状），直观反映物体的分类和定位信息。这一分区显示设计结合65 MHz点时钟和DDR3的Burst读写机制，确保视频流的低延迟传输和稳定输出，单帧处理延迟控制在50毫秒以内。

## 5.6 低延迟高精度距离反馈集成

通过I²C接口与VL6180X距离传感器通信，Delta机械臂末端实现了0至10厘米的实时测距功能，测量精度优于±1mm。设计引入了5次采样中值滤波算法，FPGA缓存连续5次测量值并取中值，显著抑制了工业环境中振动和复杂光照（如阴影或强光反射）引起的噪声干扰。这一高精度距离反馈被无缝融入机械臂控制流程，动态调整吸盘下降高度，使拾取失败率从初始的约10%降至5%以下。

VL6180X的高精度测距和快速响应与FPGA的高效处理能力相结合，确保了系统在动态环境下的适应性和可靠性。这一创新不仅提升了分拣任务的成功率，还为机械臂在复杂工业场景中的精准操作提供了技术保障，展现了低延迟高精度反馈的集成优势。

# 6 总结

本作品成功设计并实现了一个基于紫光同创PGL22G FPGA平台的工业分拣系统，通过Delta机械臂与平行四边形连杆机械臂的协同工作，完成了智能分拣任务，模拟了工业流水线场景下的多机器人低延迟、高精度协同控制需求。

## 6.1 功能实现

作品覆盖了赛题的基础与进阶任务，实现了完整的工业分拣流程：

- 运动控制：Delta机械臂通过门型路径规划实现精准拾取与放置，单次操作耗时2秒，定位精度±1毫米；平行四边形连杆机械臂通过磁吸搬运托盘，Y轴范围扩展至-300至700毫米，单次搬运耗时5秒，定位误差±2毫米。步进电机梯度加减速算法和逆运动学解算模块（Verilog实现）确保了运动的平滑性和精确性。
- 目标识别：利用双目摄像头（OV5640，720P）采集数据，通过HSV色彩空间转换识别红、黄、蓝、绿四种颜色，结合投影分析和面积阈值（圆形6700-8000，正方形8000-10000，六边形4000-6700）区分三种形状（圆形、正方形、六边形）。识别耗时约50.5毫秒。
- 传感器集成：通过I²C接口与VL6180X测距传感器通信，Delta机械臂末端实现0-10厘米实时测距，精度±1mm，结合中值滤波降低拾取失败率至5%以下。RFID模块读取托盘编号，模拟物流场景。
- 人机交互：上位机基于Qt框架（QML+C++）开发，支持手动输入坐标和预设路径控制，动态展示机械臂姿态。HDMI模块以1024×768@60 Hz分辨率分区显示双目摄像头数据，结合边缘检测和画框标注，直观呈现识别结果。语音模块实时播报拾取信息，提升交互便利性。
- 多机器人协作：Delta机械臂每三次拾取后复位（通过限位开关），连杆机械臂同时搬运托盘，协作效率提升20%以上，平均分拣周期缩短至20秒。

## 6.2 技术创新

作品在多个方面实现了技术创新：

- 逆运动学解算优化：利用FPGA并行计算和流水线设计，解算速度提升至4.7微秒（235个时钟周期，50 MHz主频），比传统MCU方案（50-100微秒）快10倍以上。数据放大策略（坐标16倍、中间参数65536倍、角度256倍）和移位操作确保定点运算精度，误差仅0.0048°。
- 资源优化：通过乘法器分时复用，将APM占用从123个降至16个（Delta和连杆机械臂各8个），在PGL22G芯片（30个APM）上实现双模块集成，逻辑资源利用率77%，布局布线通过。
- 双目摄像头分区显示：HDMI模块通过两个video_rect_read_data模块分区显示双路视频，结合65 MHz点时钟和DDR3 Burst读写，延迟16.7毫秒以内，填补了传统单路显示的不足。
- 高精度距离反馈：VL6180X测距与FPGA控制集成，结合5次采样中值滤波，提升了复杂环境下的稳定性，拾取成功率达95%以上。

## 6.3 性能表现

系统在性能测试中表现优异：

- 实时性：逆运动学解算4.7微秒，满足任务需求；颜色与形状识别耗时50.5毫秒，需进一步优化以达到33毫秒目标。
- 精度：物体定位精度±1毫米，机械臂运动精度±1毫米（Delta）和±2毫米（连杆），测距精度±1毫米。
- 稳定性：连续运行无任务冲突或机械故障，同步带打滑问题通过速度优化解决，振动显著减少。
- 资源利用：APM利用率100%，逻辑资源77%，接近芯片极限，但功能实现稳定，验证了优化策略的有效性。

## 6.4 应用价值

本作品贴近工业自动化场景，成果可广泛应用于智能分拣、物流运输和柔性制造领域。双机械臂协同设计提高了流水线效率，低延迟高精度反馈适应了复杂环境，模块化设计和资源优化策略为FPGA在工业控制中的应用提供了参考。未来可通过引入更高性能芯片、优化识别速度及完善立体视觉算法，进一步提升系统的实时性和适应性，为工业4.0的智能化发展贡献力量。

# 7 参考文献

[1]李浩然,李明桧,甄国涌,等.FPGA智驱多通道步进电机精密平台[J].工业仪表与自动化装置,2025,(01):103-110.DOI:10.19950/j.cnki.CN61-1121/TH.2025.01.019.

[2]张伟涛,全英汇,袁晓光,等.基于可重构微处理器的步进电机控制实验设计[J].电气电子教学学报,2024,46(06):195-199.

[3]张勇,张宪民,胡俊峰,等.高速并联机械手最优时间轨迹规划及实现[J].机电工程技术,2010,39(10):42-45+108.

[4]刘丹丹,王珺,刘杰,等.一种自适应的双臂协作码垛机器人的研发[J].机械设计与制造工程,2023,52(10):79-83.

[5]朱训栋,徐海港,赵栋杰.码垛机械臂运动学位置正逆解分析[J].农业工程,2017,7(04):155-158.

[6]黎显伟.码垛机器人的分类及应用[J].机械,2018,45(03):29-34+42.

[7]梁礼群.自动化生产线搬运机械手设计研究[J].组合机床与自动化加工技术,2018,(04):162-164.DOI:10.13462/j.cnki.mmtamt.2018.04.039.

[8]杨志杰,王平浩,郑勇.RFID标签印刷写卡一体机机械结构设计与实现[J].物联网技术,2024,14(07):120-123.DOI:10.16667/j.issn.2095-1302.2024.07.032.

[9]D. Austin, "Generate stepper-motor speed profiles in real time," Embedded Systems Programming, Jan. 2005.

[10] H. Hadfield, L. Wei & J. Lasenby, "The Forward and Inverse Kinematics of a Delta Robot," Advances in Computer Graphics (CGI 2020), Lecture Notes in Computer Science (LNIP, volume 12221), 2020, pp. 447-458.

[11] F. Pierrot, C. Reynaud & A. Fournier, "DELTA: a simple and efficient parallel robot," Robotica, Volume 8, Issue 2, April 1990, pp. 105-109.

[12]R. Andraka, "A survey of CORDIC algorithms for FPGA based computers," Proceedings of the 1998 ACM/SIGDA Sixth International Symposium on Field Programmable Gate Arrays, 1998, pp. 191-200.

[13]P. Chen, M. Gao, J. Huang, Y. Yang and Y. Zeng, "High-Speed Color Sorting Algorithm Based on FPGA Implementation," 2018 IEEE 27th International Symposium on Industrial Electronics (ISIE), Cairns, QLD, Australia, 2018, pp. 235-239, doi: 10.1109/ISIE.2018.8433831.

[14] Y. -S. Kung, K. -H. Tseng, C. -S. Chen, H. -Z. Sze and A. -P. Wang, "FPGA-Implementation of Inverse Kinematics and Servo Controller for Robot Manipulator," 2006 IEEE International Conference on Robotics and Biomimetics, Kunming, China, 2006, pp. 1163-1168, doi: 10.1109/ROBIO.2006.340093.

[15] V. D. Cong, "Visual servoing control of 4-DOF palletizing robotic arm for vision based sorting system," International Journal on Interactive Design and Manufacturing (IJIDeM), 2023, 17, pp. 717-728.

[16] R. Szczepanski, K. Erwinski, M. Tejer, A. Bereit & T. Tarczewski, "Optimal scheduling for palletizing task using robotic arm and artificial bee colony," Engineering Applications of Artificial Intelligence, 2022, 113, 104976.

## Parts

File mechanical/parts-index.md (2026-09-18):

# SolidWorks 文件索引

以下文件按作者确认属于本人建模，机构总体方案来自网络 STL；个人工作为补充设计与建模。原文件名保持不变，未逐项推断零件改动幅度。

| 原目录 | 文件 | 类型 |
| --- | --- | --- |
| Delta建模 | [RFID安装.SLDPRT](<solidworks/Delta建模/RFID安装.SLDPRT>) | SLDPRT |
| Delta建模 | [传送带支撑.SLDPRT](<solidworks/Delta建模/传送带支撑.SLDPRT>) | SLDPRT |
| Delta建模 | [传送带电机固定.SLDPRT](<solidworks/Delta建模/传送带电机固定.SLDPRT>) | SLDPRT |
| Delta建模 | [摄像头板卡固定连接.SLDPRT](<solidworks/Delta建模/摄像头板卡固定连接.SLDPRT>) | SLDPRT |
| Delta建模 | [板卡摄像头支架.SLDPRT](<solidworks/Delta建模/板卡摄像头支架.SLDPRT>) | SLDPRT |
| Delta建模 | [托盘放置.SLDPRT](<solidworks/Delta建模/托盘放置.SLDPRT>) | SLDPRT |
| Delta建模 | [圆柱.SLDPRT](<solidworks/Delta建模/圆柱.SLDPRT>) | SLDPRT |
| Delta建模 | [滑台底部.SLDPRT](<solidworks/Delta建模/滑台底部.SLDPRT>) | SLDPRT |
| Delta建模 | [板卡支撑 2.SLDPRT](<solidworks/Delta建模/板卡支撑 2.SLDPRT>) | SLDPRT |
| Delta建模 | [LED支架.SLDPRT](<solidworks/Delta建模/LED支架.SLDPRT>) | SLDPRT |
| Delta建模 | [距离固定杆.SLDPRT](<solidworks/Delta建模/距离固定杆.SLDPRT>) | SLDPRT |
| Delta建模 | [托盘.SLDPRT](<solidworks/Delta建模/托盘.SLDPRT>) | SLDPRT |
| Delta建模 | [抓夹连接件3.0.SLDPRT](<solidworks/Delta建模/抓夹连接件3.0.SLDPRT>) | SLDPRT |
| Delta建模 | [主动臂.SLDPRT](<solidworks/Delta建模/主动臂.SLDPRT>) | SLDPRT |
| Delta建模 | [传送带固定1.SLDPRT](<solidworks/Delta建模/传送带固定1.SLDPRT>) | SLDPRT |
| Delta建模 | [传送带滚轮支撑.SLDPRT](<solidworks/Delta建模/传送带滚轮支撑.SLDPRT>) | SLDPRT |
| Delta建模 | [距离固定.SLDPRT](<solidworks/Delta建模/距离固定.SLDPRT>) | SLDPRT |
| Delta建模 | [按钮固定.SLDPRT](<solidworks/Delta建模/按钮固定.SLDPRT>) | SLDPRT |
| Delta建模 | [正方体.SLDPRT](<solidworks/Delta建模/正方体.SLDPRT>) | SLDPRT |
| Delta建模 | [电源固定件.SLDPRT](<solidworks/Delta建模/电源固定件.SLDPRT>) | SLDPRT |
| Delta建模 | [板卡支撑1.SLDPRT](<solidworks/Delta建模/板卡支撑1.SLDPRT>) | SLDPRT |
| Delta建模 | [置物架.SLDPRT](<solidworks/Delta建模/置物架.SLDPRT>) | SLDPRT |
| Delta建模 | [限位开关.SLDPRT](<solidworks/Delta建模/限位开关.SLDPRT>) | SLDPRT |
| Delta建模 | [圆柱体.SLDPRT](<solidworks/Delta建模/圆柱体.SLDPRT>) | SLDPRT |
| Delta建模 | [托盘放置固定.SLDPRT](<solidworks/Delta建模/托盘放置固定.SLDPRT>) | SLDPRT |
| Delta建模 | [显示屏固定.SLDPRT](<solidworks/Delta建模/显示屏固定.SLDPRT>) | SLDPRT |
| Delta建模 | [末端激光安装.SLDPRT](<solidworks/Delta建模/末端激光安装.SLDPRT>) | SLDPRT |
| Delta建模 | [六边形.SLDPRT](<solidworks/Delta建模/六边形.SLDPRT>) | SLDPRT |
| Delta建模 | [滑台上部.SLDPRT](<solidworks/Delta建模/滑台上部.SLDPRT>) | SLDPRT |
| Delta建模 | [PCB盖.SLDPRT](<solidworks/Delta建模/PCB盖.SLDPRT>) | SLDPRT |
| Delta建模 | [六边体.SLDPRT](<solidworks/Delta建模/六边体.SLDPRT>) | SLDPRT |
| Delta建模 | [小角码.SLDPRT](<solidworks/Delta建模/小角码.SLDPRT>) | SLDPRT |
| Delta建模 | [传送带固定2.SLDPRT](<solidworks/Delta建模/传送带固定2.SLDPRT>) | SLDPRT |
| 2022delta | [传送带步进驱动支架.SLDPRT](<solidworks/2022delta/传送带步进驱动支架.SLDPRT>) | SLDPRT |
| 2022delta | [吸盘支架.SLDPRT](<solidworks/2022delta/吸盘支架.SLDPRT>) | SLDPRT |
| 2022delta | [正方形物料橙.SLDPRT](<solidworks/2022delta/正方形物料橙.SLDPRT>) | SLDPRT |
| 2022delta | [摄像头支架负60°.SLDPRT](<solidworks/2022delta/摄像头支架负60°.SLDPRT>) | SLDPRT |
| 2022delta | [铝型材框架20100.SLDPRT](<solidworks/2022delta/铝型材框架20100.SLDPRT>) | SLDPRT |
| 2022delta | [M3推拉杆轴.SLDPRT](<solidworks/2022delta/M3推拉杆轴.SLDPRT>) | SLDPRT |
| 2022delta | [球头拉杆.SLDPRT](<solidworks/2022delta/球头拉杆.SLDPRT>) | SLDPRT |
| 2022delta | [42步进.SLDPRT](<solidworks/2022delta/42步进.SLDPRT>) | SLDPRT |
| 2022delta | [吸盘.SLDPRT](<solidworks/2022delta/吸盘.SLDPRT>) | SLDPRT |
| 2022delta | [新主动臂.SLDPRT](<solidworks/2022delta/新主动臂.SLDPRT>) | SLDPRT |
| 2022delta | [显示屏.SLDPRT](<solidworks/2022delta/显示屏.SLDPRT>) | SLDPRT |
| 2022delta | [装配体铝型材20100.SLDASM](<solidworks/2022delta/装配体铝型材20100.SLDASM>) | SLDASM |
| 2022delta | [传送带固定件2.SLDPRT](<solidworks/2022delta/传送带固定件2.SLDPRT>) | SLDPRT |
| 2022delta | [摄像头支架负负60°.SLDPRT](<solidworks/2022delta/摄像头支架负负60°.SLDPRT>) | SLDPRT |
| 2022delta | [铝型材框架.SLDPRT](<solidworks/2022delta/铝型材框架.SLDPRT>) | SLDPRT |
| 2022delta | [光轴8_106.SLDPRT](<solidworks/2022delta/光轴8_106.SLDPRT>) | SLDPRT |
| 2022delta | [鱼眼轴承.SLDPRT](<solidworks/2022delta/鱼眼轴承.SLDPRT>) | SLDPRT |
| 2022delta | [M5_15.SLDPRT](<solidworks/2022delta/M5_15.SLDPRT>) | SLDPRT |
| 2022delta | [传送带固定件1.SLDPRT](<solidworks/2022delta/传送带固定件1.SLDPRT>) | SLDPRT |
| 2022delta | [新静止端.SLDPRT](<solidworks/2022delta/新静止端.SLDPRT>) | SLDPRT |
| 2022delta | [步进套筒.SLDPRT](<solidworks/2022delta/步进套筒.SLDPRT>) | SLDPRT |
| 2022delta | [传送带412.SLDPRT](<solidworks/2022delta/传送带412.SLDPRT>) | SLDPRT |
| 2022delta | [物料圆柱白.SLDPRT](<solidworks/2022delta/物料圆柱白.SLDPRT>) | SLDPRT |
| 2022delta | [摄像头支架正60°.SLDPRT](<solidworks/2022delta/摄像头支架正60°.SLDPRT>) | SLDPRT |
| 2022delta | [舵机.SLDPRT](<solidworks/2022delta/舵机.SLDPRT>) | SLDPRT |
| 2022delta | [执行端.SLDPRT](<solidworks/2022delta/执行端.SLDPRT>) | SLDPRT |
| 2022delta | [三角物料蓝.SLDPRT](<solidworks/2022delta/三角物料蓝.SLDPRT>) | SLDPRT |
| 2022delta | [关节连接轴.SLDPRT](<solidworks/2022delta/关节连接轴.SLDPRT>) | SLDPRT |
| 2022delta | [物料槽.SLDPRT](<solidworks/2022delta/物料槽.SLDPRT>) | SLDPRT |
| 2022delta | [delta框架.SLDASM](<solidworks/2022delta/delta框架.SLDASM>) | SLDASM |
| 2022delta | [M4_15.SLDPRT](<solidworks/2022delta/M4_15.SLDPRT>) | SLDPRT |
| Delta建模 | [变速箱内部.SLDPRT](<solidworks/Delta建模/Delta-X-3D打印部分/STL/7变速箱内部零件/变速箱内部.SLDPRT>) | SLDPRT |
| Delta建模 | [变速箱内部.SLDASM](<solidworks/Delta建模/Delta-X-3D打印部分/STL/7变速箱内部零件/变速箱内部.SLDASM>) | SLDASM |
| 带滑轨的步进电机机械臂 | [延长杆底座接收.SLDPRT](<solidworks/带滑轨的步进电机机械臂/流水线/延长杆底座接收.SLDPRT>) | SLDPRT |
| 带滑轨的步进电机机械臂 | [紧张环9.SLDPRT](<solidworks/带滑轨的步进电机机械臂/流水线/紧张环9.SLDPRT>) | SLDPRT |
| 带滑轨的步进电机机械臂 | [2020脚.SLDPRT](<solidworks/带滑轨的步进电机机械臂/流水线/2020脚.SLDPRT>) | SLDPRT |
| 带滑轨的步进电机机械臂 | [摄像头支架.SLDPRT](<solidworks/带滑轨的步进电机机械臂/流水线/摄像头支架.SLDPRT>) | SLDPRT |
| 带滑轨的步进电机机械臂 | [距离固定杆.SLDPRT](<solidworks/带滑轨的步进电机机械臂/流水线/距离固定杆.SLDPRT>) | SLDPRT |
| 带滑轨的步进电机机械臂 | [距离固定.SLDPRT](<solidworks/带滑轨的步进电机机械臂/流水线/距离固定.SLDPRT>) | SLDPRT |
| 带滑轨的步进电机机械臂 | [盒子.SLDPRT](<solidworks/带滑轨的步进电机机械臂/流水线/盒子.SLDPRT>) | SLDPRT |
| 带滑轨的步进电机机械臂 | [延长杆10接收.SLDPRT](<solidworks/带滑轨的步进电机机械臂/流水线/延长杆10接收.SLDPRT>) | SLDPRT |
| 带滑轨的步进电机机械臂 | [接收盖.SLDPRT](<solidworks/带滑轨的步进电机机械臂/流水线/接收盖.SLDPRT>) | SLDPRT |
| 带滑轨的步进电机机械臂 | [传输带紧张.SLDPRT](<solidworks/带滑轨的步进电机机械臂/流水线/传输带紧张.SLDPRT>) | SLDPRT |
| 带滑轨的步进电机机械臂 | [轴承支撑..SLDPRT](<solidworks/带滑轨的步进电机机械臂/流水线/轴承支撑..SLDPRT>) | SLDPRT |
| 带滑轨的步进电机机械臂 | [板卡支撑连接接收.SLDPRT](<solidworks/带滑轨的步进电机机械臂/流水线/板卡支撑连接接收.SLDPRT>) | SLDPRT |
| 带滑轨的步进电机机械臂 | [延长杆10发送.SLDPRT](<solidworks/带滑轨的步进电机机械臂/流水线/延长杆10发送.SLDPRT>) | SLDPRT |
| 带滑轨的步进电机机械臂 | [传输带支撑.SLDPRT](<solidworks/带滑轨的步进电机机械臂/流水线/传输带支撑.SLDPRT>) | SLDPRT |
| 带滑轨的步进电机机械臂 | [步进电机支架.SLDPRT](<solidworks/带滑轨的步进电机机械臂/流水线/步进电机支架.SLDPRT>) | SLDPRT |
| 带滑轨的步进电机机械臂 | [板卡支撑连接发送.SLDPRT](<solidworks/带滑轨的步进电机机械臂/流水线/板卡支撑连接发送.SLDPRT>) | SLDPRT |
| 带滑轨的步进电机机械臂 | [2020支架.SLDPRT](<solidworks/带滑轨的步进电机机械臂/流水线/2020支架.SLDPRT>) | SLDPRT |
| 带滑轨的步进电机机械臂 | [延长杆底座发送.SLDPRT](<solidworks/带滑轨的步进电机机械臂/流水线/延长杆底座发送.SLDPRT>) | SLDPRT |
| 带滑轨的步进电机机械臂 | [摄像头支架盖.SLDPRT](<solidworks/带滑轨的步进电机机械臂/流水线/摄像头支架盖.SLDPRT>) | SLDPRT |
| 带滑轨的步进电机机械臂 | [2020连接.SLDPRT](<solidworks/带滑轨的步进电机机械臂/流水线/2020连接.SLDPRT>) | SLDPRT |
| 带滑轨的步进电机机械臂 | [板卡支撑.SLDPRT](<solidworks/带滑轨的步进电机机械臂/流水线/板卡支撑.SLDPRT>) | SLDPRT |
| 带滑轨的步进电机机械臂 | [泵托.SLDPRT](<solidworks/带滑轨的步进电机机械臂/机械臂/泵托.SLDPRT>) | SLDPRT |
| 带滑轨的步进电机机械臂 | [泵托盖.SLDPRT](<solidworks/带滑轨的步进电机机械臂/机械臂/泵托盖.SLDPRT>) | SLDPRT |
| 带滑轨的步进电机机械臂 | [抓夹连接件2.0.SLDPRT](<solidworks/带滑轨的步进电机机械臂/stp/抓夹stp/抓夹连接件2.0.SLDPRT>) | SLDPRT |
| 带滑轨的步进电机机械臂 | [抓夹连接件3.0.SLDPRT](<solidworks/带滑轨的步进电机机械臂/stp/抓夹stp/抓夹连接件3.0.SLDPRT>) | SLDPRT |
| 带滑轨的步进电机机械臂 | [抓夹连接件1.0.SLDPRT](<solidworks/带滑轨的步进电机机械臂/stp/抓夹stp/抓夹连接件1.0.SLDPRT>) | SLDPRT |
| 带滑轨的步进电机机械臂 | [2020脚.SLDPRT](<solidworks/带滑轨的步进电机机械臂/stp/轨道stp/2020脚.SLDPRT>) | SLDPRT |
| 带滑轨的步进电机机械臂 | [滑环加0.2.SLDPRT](<solidworks/带滑轨的步进电机机械臂/stp/轨道stp/滑环加0.2.SLDPRT>) | SLDPRT |
| 带滑轨的步进电机机械臂 | [拖链连接件.SLDPRT](<solidworks/带滑轨的步进电机机械臂/stp/轨道stp/拖链连接件.SLDPRT>) | SLDPRT |
| 带滑轨的步进电机机械臂 | [电源安装件.SLDPRT](<solidworks/带滑轨的步进电机机械臂/stp/轨道stp/电源安装件.SLDPRT>) | SLDPRT |

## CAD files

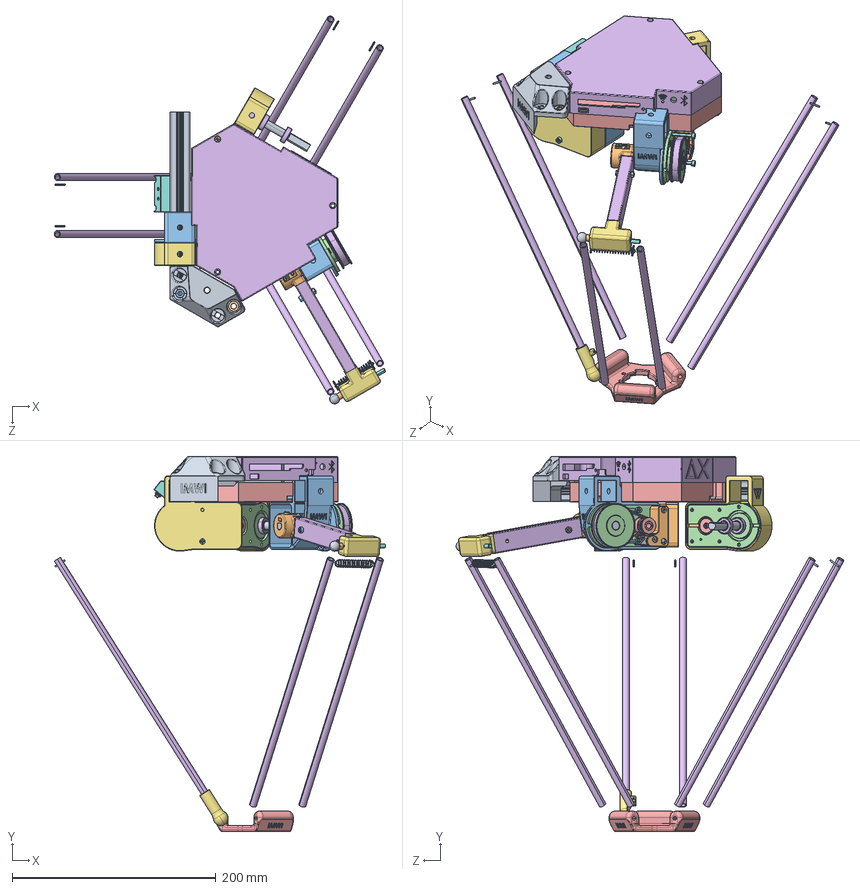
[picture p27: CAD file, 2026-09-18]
mechanical/solidworks/Delta建模/Delta-X-3D打印部分/STL/7变速箱内部零件/变速箱内部.SLDASM
325.7 x 368.5 x 381.1 mm
inox8.STEP x 3
cacbon.STEP x 6
Spring Stick.STEP x 6
Alu plate increase hardness.STEP x 3
Bearing 5_16.STEP x 3
BeltTensioner.STEP x 3
BeltTensioner2.STEP x 3
BeltTensionerBase-v1.STEP x 3
M3x12 bolt_M3x8 bolt.STEP x 3
M3 Nut_M3 Nut.STEP x 5
Cross M3x10 bolt_Cross M3x10 bolt.STEP x 2
GearboxLid V2.STEP
ring 8mm.STEP x 2
GearboxBody V2.STEP
M3x30 bolt_M3x8 bolt.STEP x 2
Bearing 8_16.STEP x 4
GearBoxSprings.STEP x 2
GT2_60T_8.STEP x 3
GT2_20T_5_____________1.STEP x 3
Belt1-1^Delta X 1.STEP x 3

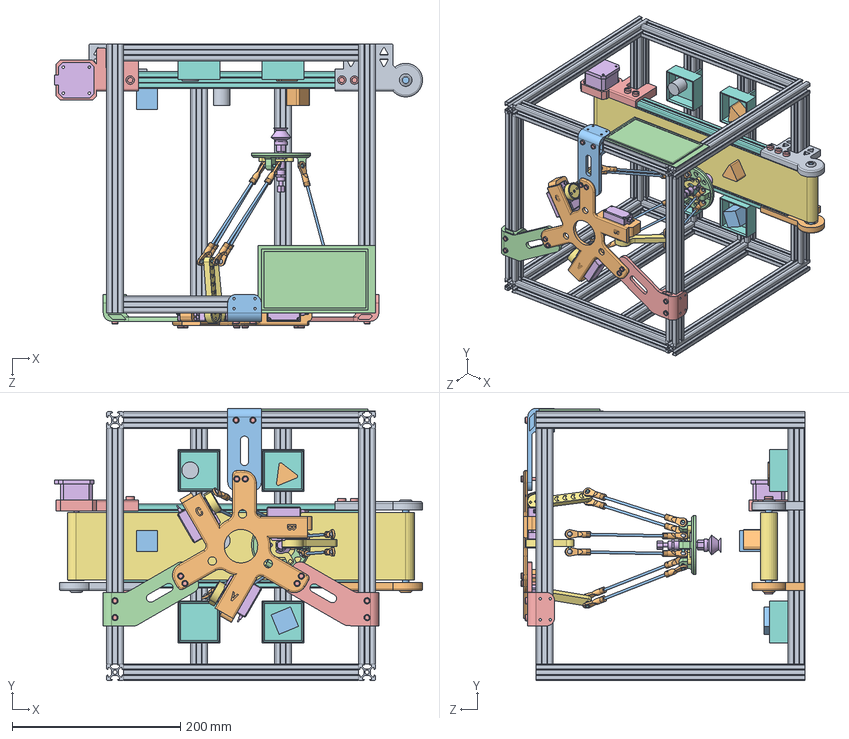
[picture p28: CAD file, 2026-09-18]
mechanical/solidworks/2022delta/delta框架.SLDASM
437.9 x 324.0 x 338.0 mm
铝型材框架
新静止端
摄像头支架正60°
摄像头支架负60°
摄像头支架负负60°
舵机 x 3
新主动臂 x 3
关节连接轴 x 6
鱼眼轴承 x 12
球头拉杆 x 12
M3推拉杆轴 x 6
执行端
M4_15 x 12
吸盘
吸盘支架
铝型材框架20100 x 5
传送带固定件1 x 2
传送带固定件2
光轴8_106
步进套筒 x 2
传送带步进驱动支架
42步进
传送带412
物料槽 x 4
物料圆柱白 x 2
三角物料蓝 x 2
正方形物料橙 x 2
显示屏
M5_15 x 11

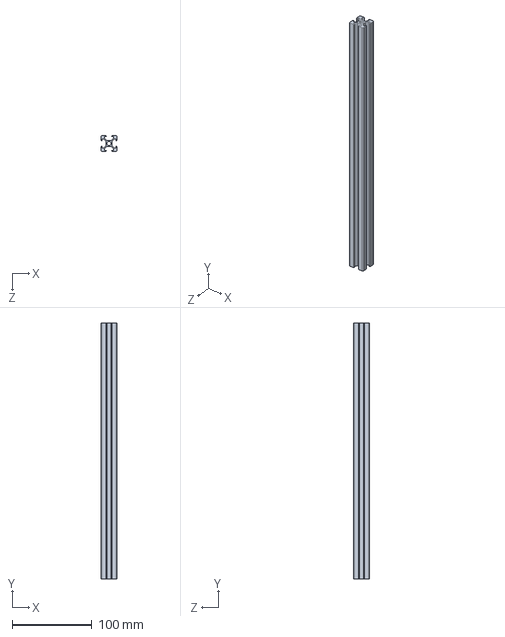
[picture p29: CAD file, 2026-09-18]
mechanical/solidworks/2022delta/铝型材框架20100.SLDPRT
20.0 x 320.0 x 20.0 mm

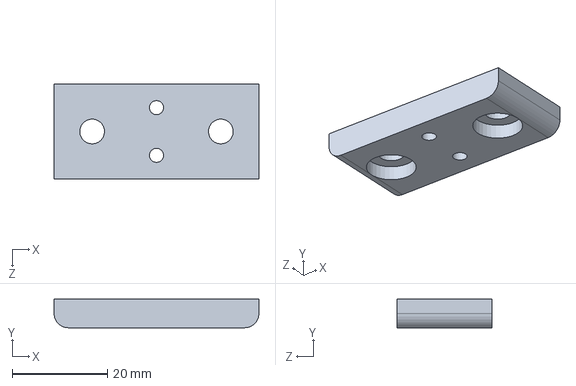
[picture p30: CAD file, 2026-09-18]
mechanical/solidworks/Delta建模/托盘放置固定.SLDPRT
43.0 x 6.00 x 20.0 mm

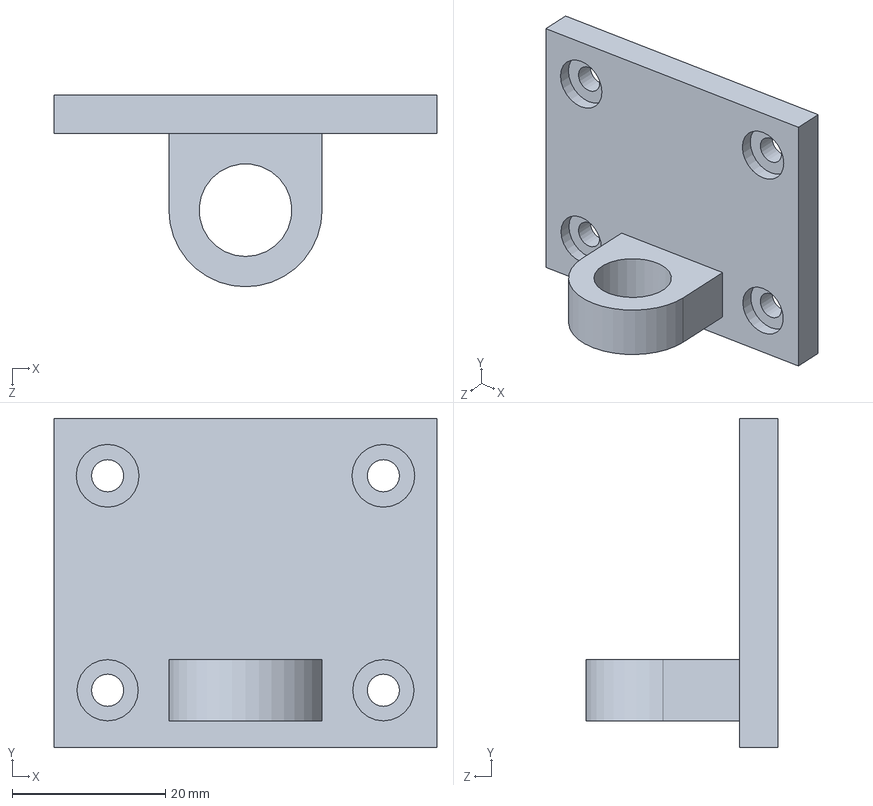
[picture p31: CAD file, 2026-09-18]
mechanical/solidworks/带滑轨的步进电机机械臂/stp/抓夹stp/抓夹连接件3.0.SLDPRT
50.0 x 43.0 x 25.0 mm

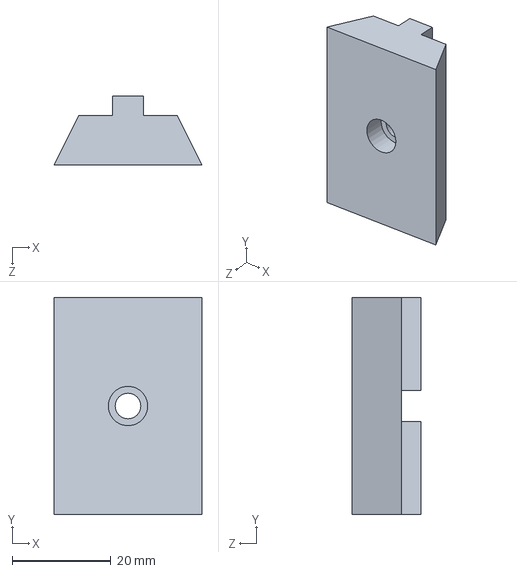
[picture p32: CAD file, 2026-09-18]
mechanical/solidworks/带滑轨的步进电机机械臂/stp/轨道stp/2020脚.SLDPRT
30.0 x 44.0 x 14.0 mm

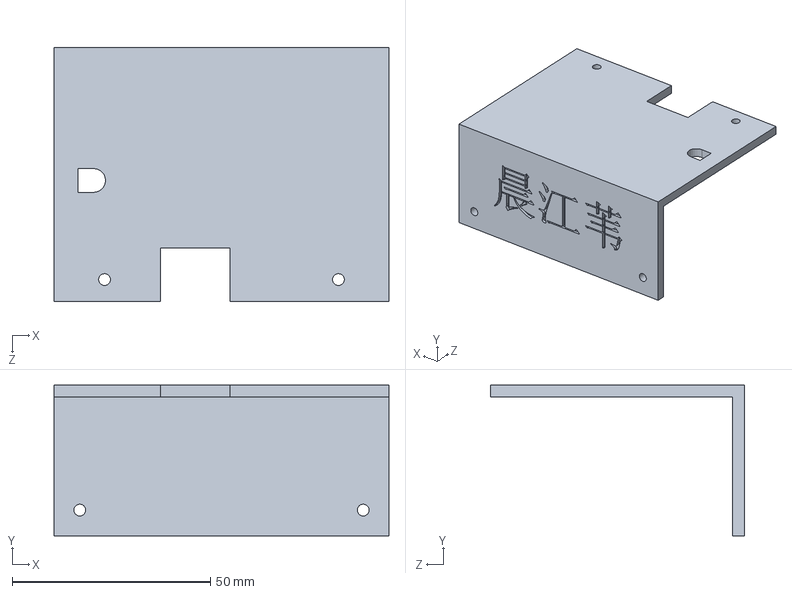
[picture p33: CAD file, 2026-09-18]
mechanical/solidworks/带滑轨的步进电机机械臂/机械臂/泵托盖.SLDPRT
84.5 x 38.0 x 64.0 mm

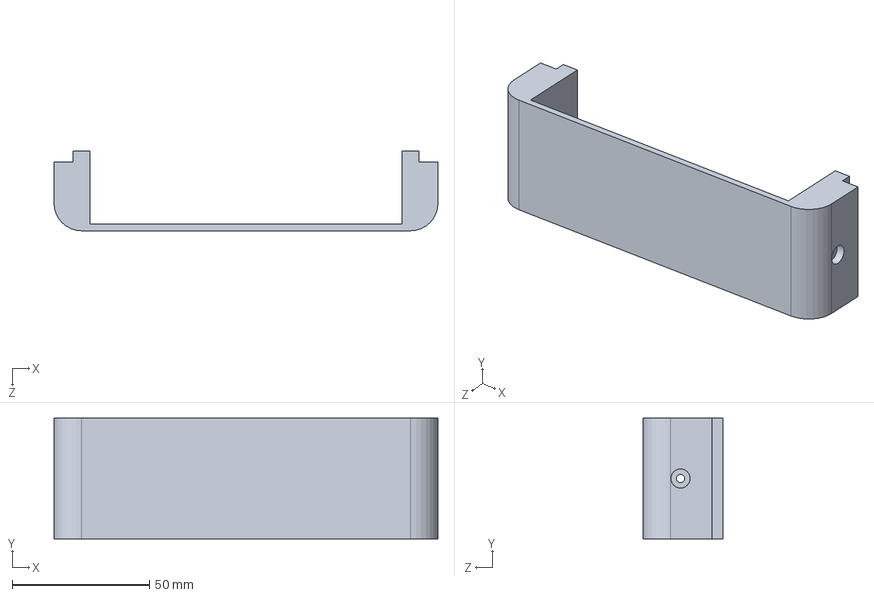
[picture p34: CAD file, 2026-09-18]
mechanical/solidworks/带滑轨的步进电机机械臂/流水线/传输带紧张.SLDPRT
140.0 x 44.0 x 29.0 mm

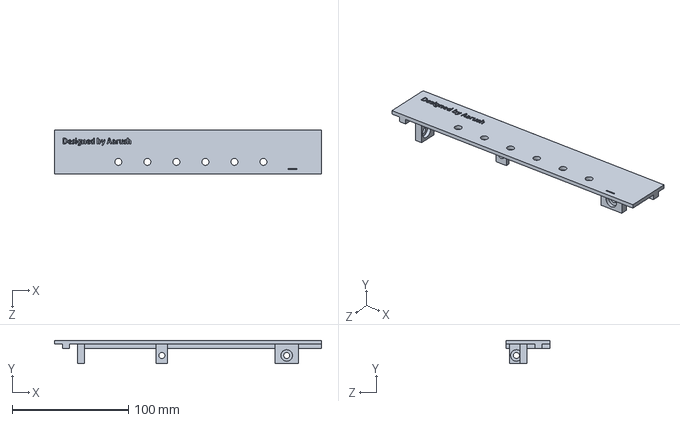
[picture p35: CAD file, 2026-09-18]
mechanical/solidworks/Delta建模/按钮固定.SLDPRT
230.0 x 20.0 x 38.0 mm

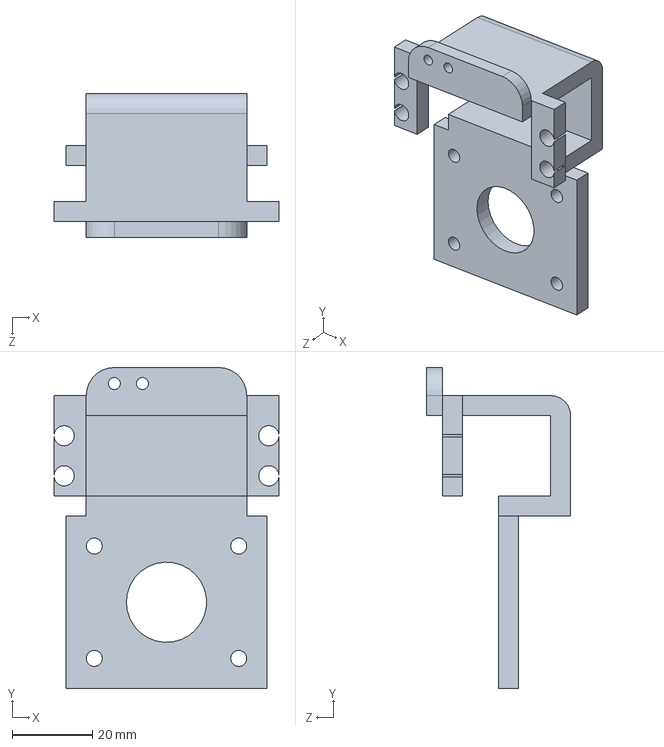
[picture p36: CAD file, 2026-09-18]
mechanical/solidworks/带滑轨的步进电机机械臂/stp/抓夹stp/抓夹连接件1.0.SLDPRT
56.0 x 80.0 x 36.0 mm

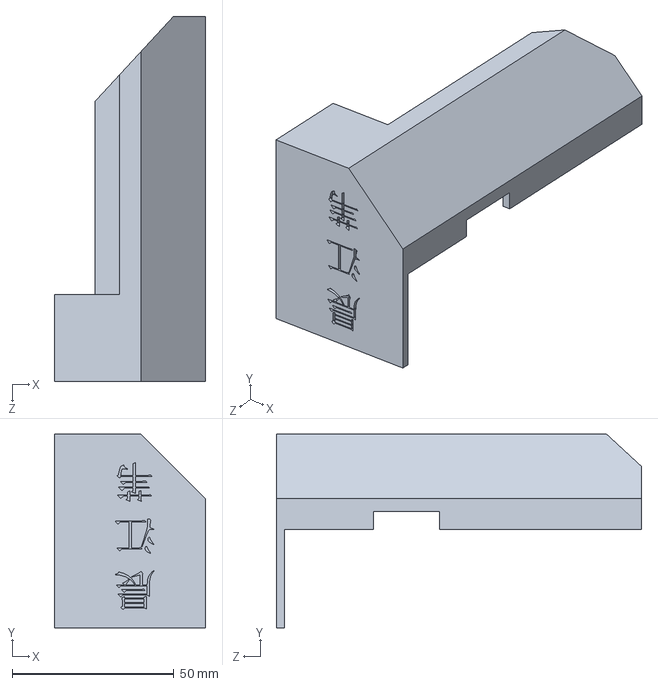
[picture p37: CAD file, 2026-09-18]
mechanical/solidworks/带滑轨的步进电机机械臂/stp/轨道stp/电源安装件.SLDPRT
46.8 x 60.0 x 113.0 mm

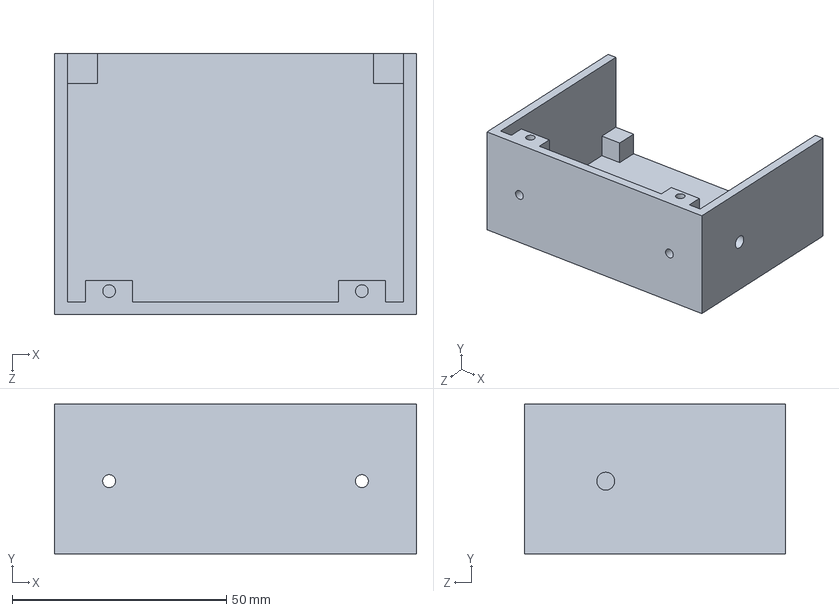
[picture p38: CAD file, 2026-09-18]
mechanical/solidworks/带滑轨的步进电机机械臂/机械臂/泵托.SLDPRT
84.5 x 35.0 x 61.0 mm

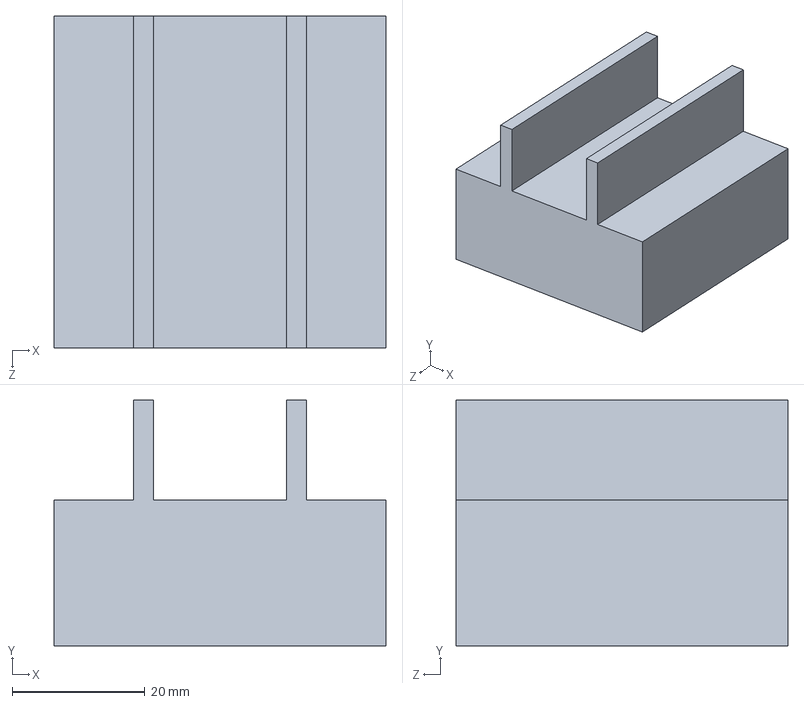
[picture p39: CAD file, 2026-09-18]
mechanical/solidworks/2022delta/物料槽.SLDPRT
50.0 x 37.0 x 50.0 mm

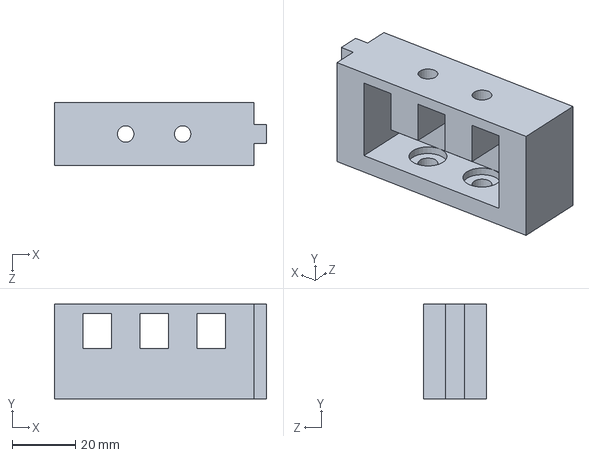
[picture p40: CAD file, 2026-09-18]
mechanical/solidworks/Delta建模/电源固定件.SLDPRT
67.0 x 30.0 x 20.0 mm

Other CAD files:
mechanical/solidworks/2022delta/装配体铝型材20100.SLDASM
mechanical/solidworks/带滑轨的步进电机机械臂/流水线/传输带支撑.SLDPRT
mechanical/solidworks/带滑轨的步进电机机械臂/stp/抓夹stp/抓夹连接件2.0.SLDPRT
mechanical/solidworks/带滑轨的步进电机机械臂/stp/轨道stp/滑环加0.2.SLDPRT
mechanical/solidworks/2022delta/42步进.SLDPRT
mechanical/solidworks/2022delta/M3推拉杆轴.SLDPRT
mechanical/solidworks/2022delta/M4_15.SLDPRT
mechanical/solidworks/2022delta/M5_15.SLDPRT
mechanical/solidworks/2022delta/三角物料蓝.SLDPRT
mechanical/solidworks/2022delta/传送带412.SLDPRT
mechanical/solidworks/2022delta/传送带固定件1.SLDPRT
mechanical/solidworks/2022delta/传送带固定件2.SLDPRT
mechanical/solidworks/2022delta/传送带步进驱动支架.SLDPRT
mechanical/solidworks/2022delta/光轴8_106.SLDPRT
mechanical/solidworks/2022delta/关节连接轴.SLDPRT
mechanical/solidworks/2022delta/吸盘.SLDPRT
mechanical/solidworks/2022delta/吸盘支架.SLDPRT
mechanical/solidworks/2022delta/执行端.SLDPRT
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

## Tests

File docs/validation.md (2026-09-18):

# 验证记录

## 历史报告证据

| 指标 | 来源 | 可得出的结论 |
| --- | --- | --- |
| Delta 235 周期 / 4.7 μs | 报告 4.1.3、图 4.1.5 | 原报告在 50 MHz 下记录的算法延迟 |
| 单点约 0.0048° 差异 | 图 4.1.3、4.1.4 | 仅对应 (0,0,−237.5 mm) 样点 |
| 两套逆解共 16 APM | 报告 4.1.4 文字 | 逆解模块统计，未由本次综合复核 |
| 整机 APM 30/30 | 图 4.1.8 | 整机统计，不是逆解模块统计 |

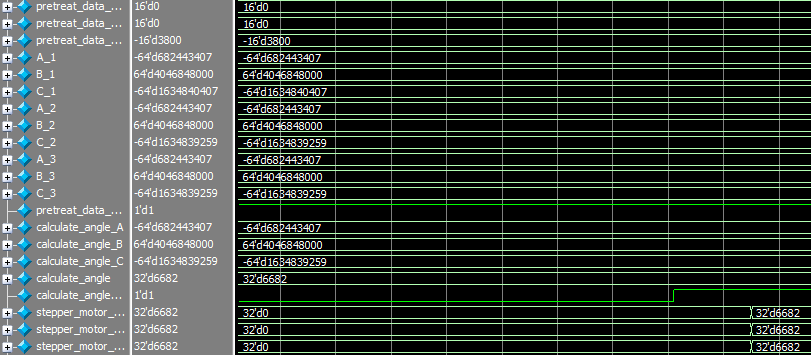
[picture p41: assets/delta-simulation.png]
原角度仿真

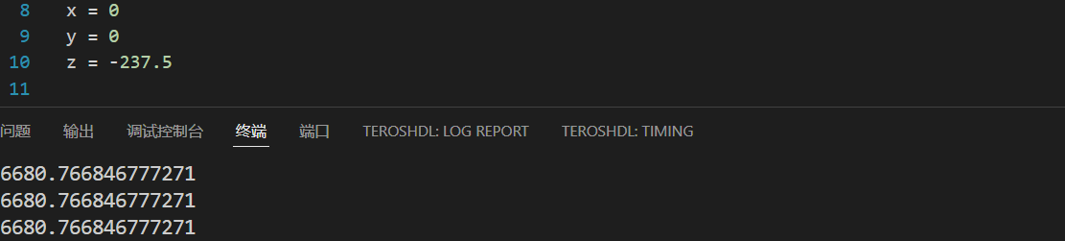
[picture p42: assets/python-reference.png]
原 Python 对照截图

原整体解算波形
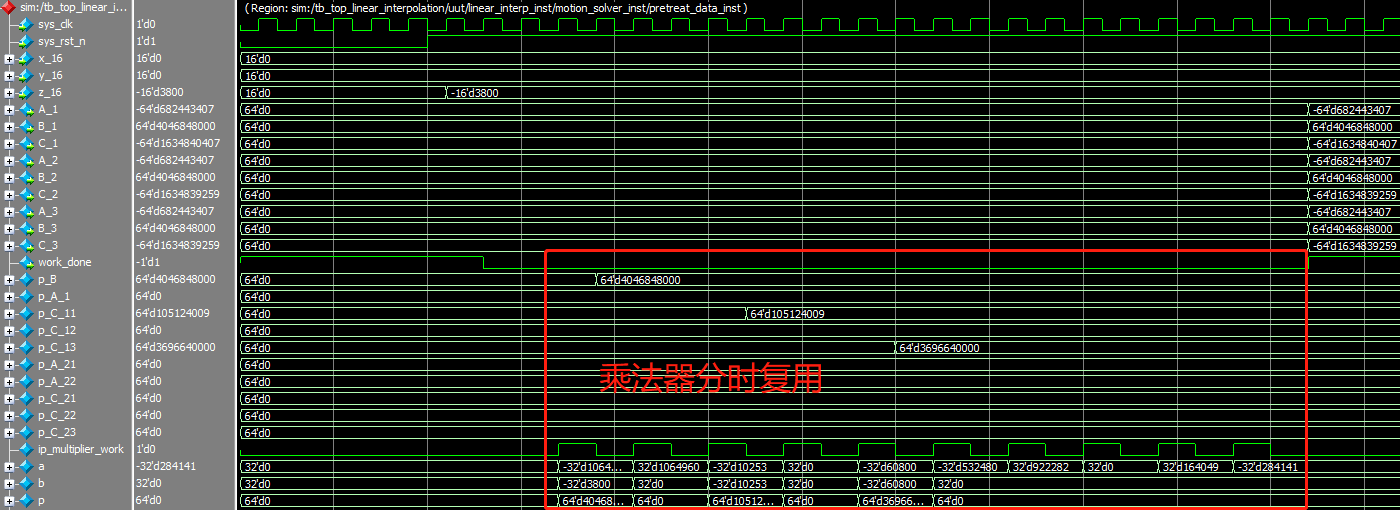
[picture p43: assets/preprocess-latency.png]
原预处理波形

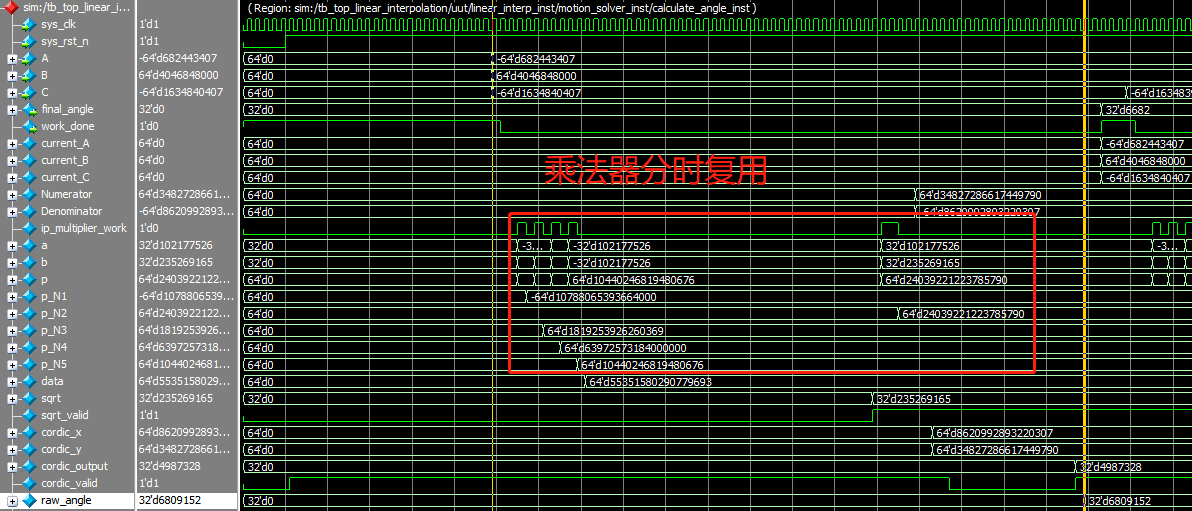
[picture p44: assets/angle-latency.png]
原单关节波形

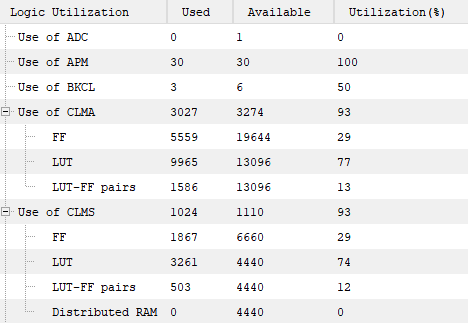
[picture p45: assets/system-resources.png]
原整机资源统计


## 本次整理验证

执行结果保存在 [整理检查记录](organization-check.json)。检查范围是源文件校验、工程输入文件路径、Markdown 本地链接及 Python 样点。`source-manifest.json` 提供文件来源和摘要。

本机执行原 Python 逆解脚本，在 (0,0,−237.5 mm) 输出三轴 ×256 角度均为 `6680.766846777271`，对应约 `26.0967455°`。报告中的文字将该数字四舍五入为 `6680.77`，因此其后续换算会略有不同。RTL 输出 `6682` 是原报告记录，并非本次重新仿真产生。

本次未执行 PDS 综合、布局布线、HDL 仿真和硬件测试。原 `tb_motion_solver.v` 属于激励和波形观察型测试，不包含自动误差断言；现存默认输入也不是报告中的 −3800 样点。

## 后续验证的明确入口

- 使用原 `sim/delta/tb_motion_solver.v`，确认生成 IP 和仿真库后再运行。
- 为报告样点设置 `x_16=0, y_16=0, z_16=-3800`，检查内部角度输出，核对采样时刻。
- 扩充多个有效坐标、工作空间边界、不可达点、象限边界、复位及重复相同输入的用例。
- 分别报告算法最大角度误差、角度量化分辨率和实物位置误差，避免将三者混用。
- 分开记录独立逆解模块与整机的资源占用、时序约束和关键路径结果。

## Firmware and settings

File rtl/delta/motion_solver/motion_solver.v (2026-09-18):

//三个主动臂角度同步解算，主动臂垂直向下为0°
//主动臂向外角度为正，范围0到140

module motion_solver
(
    input wire                  sys_clk,                // 系统时钟输入，50MHz频率    
    input wire                  sys_rst_n,              // 复位信号输入，低电平复位

    input wire signed [15:0]    x_16,                   // 放大16倍的x坐标     
    input wire signed [15:0]    y_16,                   // 放大16倍的y坐标 
    input wire signed [15:0]    z_16,                   // 放大16倍的z坐标

    output wire                 step_pulse_1,           // 步进电机的脉冲信号输出
    output wire                 direction_1,            // 步进电机的方向信号输出
    output wire                 reached_target_1,       // 目标位置标志位
    
    output wire                 step_pulse_2,           // 步进电机的脉冲信号输出
    output wire                 direction_2,            // 步进电机的方向信号输出
    output wire                 reached_target_2,       // 目标位置标志位
    
    output wire                 step_pulse_3,           // 步进电机的脉冲信号输出
    output wire                 direction_3,            // 步进电机的方向信号输出
    output wire                 reached_target_3,       // 目标位置标志位
    
    output reg                  motion_solver_work_done // 解算运动完成信号
);

//********************************************************************//
//****************** Parameter and Internal Signal *******************//
//********************************************************************//

reg  signed  [15:0] pretreat_data_x_16;     
reg  signed  [15:0] pretreat_data_y_16; 
reg  signed  [15:0] pretreat_data_z_16;
wire signed  [63:0] A_1;
wire signed  [63:0] B_1;
wire signed  [63:0] C_1;
wire signed  [63:0] A_2;
wire signed  [63:0] B_2;
wire signed  [63:0] C_2;
wire signed  [63:0] A_3;
wire signed  [63:0] B_3;
wire signed  [63:0] C_3;
wire                pretreat_data_work_done;

reg  signed  [63:0] calculate_angle_A;
reg  signed  [63:0] calculate_angle_B;
reg  signed  [63:0] calculate_angle_C;
wire         [31:0] calculate_angle;
wire                calculate_angle_work_done;

reg          [31:0] stepper_motor_angles_1;
reg          [31:0] stepper_motor_angles_2;
reg          [31:0] stepper_motor_angles_3;

reg          [31:0] target_angles_1;
reg          [31:0] target_angles_2;
reg          [31:0] target_angles_3;

reg  signed  [15:0] current_x = 0;
reg  signed  [15:0] current_y = 0;                 
reg  signed  [15:0] current_z = 0;

parameter STATE_0 = 3'b000;                           
parameter STATE_1 = 3'b001;                                                                           
parameter STATE_2 = 3'b010;                                                                           
parameter STATE_3 = 3'b011;                                                                           
parameter STATE_4 = 3'b100;                                                                           
parameter STATE_5 = 3'b101;                                                                           
parameter STATE_6 = 3'b110;                                                                           
parameter STATE_7 = 3'b111;                                                                           

reg          [2:0]  state, next_state; 
reg                 flag_0_to_1;
reg                 flag_1_to_2;
reg                 flag_2_to_3;
reg                 flag_3_to_4;
reg                 flag_4_to_5;
reg                 flag_5_to_6;
reg                 flag_6_to_7;
reg                 flag_7_to_0;
reg          [15:0] cnt;

//********************************************************************//
//************************** Submodule Inst **************************//
//********************************************************************//

pretreat_data pretreat_data_inst(
    .sys_rst_n(sys_rst_n),
    .sys_clk(sys_clk),
    .x_16(pretreat_data_x_16),     
    .y_16(pretreat_data_y_16),     
    .z_16(pretreat_data_z_16),         
    .A_1(A_1),      
    .B_1(B_1),      
    .C_1(C_1),      
    .A_2(A_2),      
    .B_2(B_2),      
    .C_2(C_2),      
    .A_3(A_3),      
    .C_3(C_3),      
    .B_3(B_3),      
    .work_done(pretreat_data_work_done)
);

calculate_angle calculate_angle_inst(
    .sys_rst_n(sys_rst_n),
    .sys_clk(sys_clk),
    .A(calculate_angle_A),        
    .B(calculate_angle_B),        
    .C(calculate_angle_C),        
    .final_angle(calculate_angle),    
    .work_done(calculate_angle_work_done) 
);

stepper_motor_ctrl stepper_motor_ctrl_inst_1(
    .sys_rst_n(sys_rst_n),
    .sys_clk(sys_clk),        
    .target_angles(stepper_motor_angles_1),    
    .step_pulse(step_pulse_1),  
    .direction(direction_1),     
    .reached_target(reached_target_1)    
);

stepper_motor_ctrl stepper_motor_ctrl_inst_2(
    .sys_rst_n(sys_rst_n),
    .sys_clk(sys_clk),       
    .target_angles(stepper_motor_angles_2),    
    .step_pulse(step_pulse_2),  
    .direction(direction_2),     
    .reached_target(reached_target_2)     
);

stepper_motor_ctrl stepper_motor_ctrl_inst_3(
    .sys_rst_n(sys_rst_n),
    .sys_clk(sys_clk),        
    .target_angles(stepper_motor_angles_3),    
    .step_pulse(step_pulse_3),  
    .direction(direction_3),     
    .reached_target(reached_target_3)     
);

//********************************************************************//
//***************************** Main Code ****************************//
//********************************************************************//

always @(posedge sys_clk or negedge sys_rst_n) begin
    if (!sys_rst_n) begin
        state <= STATE_0;             // 复位时，进入初始状态
    end else begin
        state <= next_state;          // 正常情况下，状态按时钟更新
    end
end
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

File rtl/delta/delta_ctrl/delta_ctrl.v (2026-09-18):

// 放置1到3号坐标顺序：1六边形、2圆形、3正方形
// 颜色顺序：1红、2绿、3蓝、4黄
// 面朝传送带传输方向，格子代表数字如下
// 1   2   3   4
// 5   6   7   8
// 9   10  11  12

module delta_ctrl
(
    input  wire                 sys_clk,                // 系统时钟，50MHz
    input  wire                 sys_rst_n,              // 系统复位，低电平有效
    
    input  wire                 start_inst,             // 启动初始化机械臂
    input  wire                 start_move,             // 启动运动信号

    input  wire                 data_valid,             // 输入的坐标信号有效
    
    input  wire                 limit_switch_1,         // 电机1限位开关信号
    input  wire                 limit_switch_2,         // 电机2限位开关信号
    input  wire                 limit_switch_3,         // 电机3限位开关信号
    
    input  wire        [3:0]    ltem_red_1,             // 红色六边形
    input  wire        [3:0]    ltem_red_2,             // 红色圆形
    input  wire        [3:0]    ltem_red_3,             // 红色正方形
    input  wire        [3:0]    ltem_green_1,           // 绿色六边形
    input  wire        [3:0]    ltem_green_2,           // 绿色圆形
    input  wire        [3:0]    ltem_green_3,           // 绿色正方形
    input  wire        [3:0]    ltem_blue_1,            // 蓝色六边形
    input  wire        [3:0]    ltem_blue_2,            // 蓝色圆形
    input  wire        [3:0]    ltem_blue_3,            // 蓝色正方形
    input  wire        [3:0]    ltem_yellow_1,          // 黄色六边形
    input  wire        [3:0]    ltem_yellow_2,          // 黄色圆形
    input  wire        [3:0]    ltem_yellow_3,          // 黄色正方形   

    output wire                 Delta_step_pulse_1,     // Delta机械臂电机 1 脉冲信号
    output wire                 Delta_direction_1,      // Delta机械臂电机 1 方向信号
    output wire                 Delta_step_pulse_2,     // Delta机械臂电机 2 脉冲信号
    output wire                 Delta_direction_2,      // Delta机械臂电机 2 方向信号
    output wire                 Delta_step_pulse_3,     // Delta机械臂电机 3 脉冲信号
    output wire                 Delta_direction_3,      // Delta机械臂电机 3 方向信号

    output wire                 step_pulse_1,           // 平移步进电机脉冲信号
    output wire                 direction_1,            // 平移步进电机方向信号
    output wire                 step_pulse_2,           // 旋转步进电机脉冲信号
    output wire                 direction_2,            // 旋转步进电机方向信号
    output wire                 step_pulse_3,           // 大臂步进电机脉冲信号
    output wire                 direction_3,            // 大臂步进电机方向信号
    output wire                 step_pulse_4,           // 小臂步进电机脉冲信号
    output wire                 direction_4,            // 小臂步进电机方向信号

    output reg                  electromagnet,          // 电磁铁打开信号，高电平有效    
    output reg                  sucker_pump,            // 吸盘的泵控制信号
    output reg                  sucker_valve,           // 吸盘的电磁阀控制信号

    output wire                 tx,                     // UART发送输出
    input  wire                 rx                      // 串口接收数据
);

//********************************************************************//
//****************** Parameter and Internal Signal *******************//
//********************************************************************//

parameter item_wait_z    = -16'sd4900;         // 物体上方Z坐标
parameter item_take_z    = -16'sd5028;         // 物体吸取Z坐标
parameter item_up_z      = -16'sd4000;         // 物体吸取后Z坐标
   
parameter pump_stay_time = 30000000;           // 吸盘停留时间10000000
parameter pump_put_time  = 80000000;           // 吸盘停留时间40000000               

parameter signed [15:0] target_item_put_x [0:2] = {
    -16'sd2300,                                // 物体1 x
    -16'sd2300,                                // 物体2 x
    -16'sd2300                                 // 物体3 x
};
parameter signed [15:0] target_item_put_y [0:2] = {
    -16'sd650,                                 // 物体1 y
     16'sd50,                                  // 物体2 y
     16'sd750                                  // 物体3 y
};
parameter signed [15:0] target_item_put_z [0:2] = {
    -16'sd4800,                                // 物体1 z
    -16'sd4800,                                // 物体2 z
    -16'sd4800                                 // 物体3 z
};

parameter signed [15:0] target_item_take_x [0:12] = {
     16'sd0,                                   // 空 x
    -16'sd666,                                 // 格子1 x
    -16'sd666,                                 // 格子2 x 
    -16'sd666,                                 // 格子3 x
    -16'sd666,                                 // 格子4 x
    
     16'sd0,                                   // 格子5 x
     16'sd0,                                   // 格子6 x
     16'sd0,                                   // 格子7 x
     16'sd0,                                   // 格子8 x
    
     16'sd666,                                 // 格子9 x
     16'sd666,                                 // 格子10 x
     16'sd666,                                 // 格子11 x
     16'sd666                                  // 格子12 x
};
parameter signed [15:0] target_item_take_y [0:12] = {
     16'sd0,                                   // 空 y
    -16'sd1000,                                // 格子1 y
    -16'sd330,                                 // 格子2 y
     16'sd330,                                 // 格子3 y
     16'sd1000,                                // 格子4 y
     
    -16'sd1000,                                // 格子5 y
    -16'sd330,                                 // 格子6 y
     16'sd330,                                 // 格子7 y
     16'sd1000,                                // 格子8 y
     
    -16'sd1000,                                // 格子9 y
    -16'sd330,                                 // 格子10 y
     16'sd330,                                 // 格子11 y
     16'sd1000                                 // 格子12 y
};
parameter signed [15:0] target_item_take_z [0:12] = {
     16'sd0,                                   // 空 z
    -16'sd4580,                                // 格子1 z
    -16'sd4580,                                // 格子2 z
    -16'sd4580,                                // 格子3 z
    -16'sd4580,                                // 格子4 z
    
    -16'sd4580,                                // 格子5 z
    -16'sd4580,                                // 格子6 z
    -16'sd4580,                                // 格子7 z
    -16'sd4580,                                // 格子8 z
    
    -16'sd4580,                                // 格子9 z
    -16'sd4580,                                // 格子10 z
    -16'sd4580,                                // 格子11 z
    -16'sd4580                                 // 格子12 z
};

reg signed [15:0] target_x;
reg signed [15:0] target_y;
reg signed [15:0] target_z;
reg        [31:0] delay_cnt;

reg               catch_finish;

reg               start_reset;
wire              finish_reset;

reg        [3:0]  ltem_cnt;
reg               ltem_cnt_flag;
wire              motion_done;

reg        [7:0]  pi_data;
reg               pi_flag;
wire              tx_done;
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
